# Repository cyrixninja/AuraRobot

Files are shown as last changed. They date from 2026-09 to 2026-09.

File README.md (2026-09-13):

# Aura — AI Social Assistance Robot

> A warm, voice-first companion robot that turns everyday conversation into a tangible, expressive interaction.

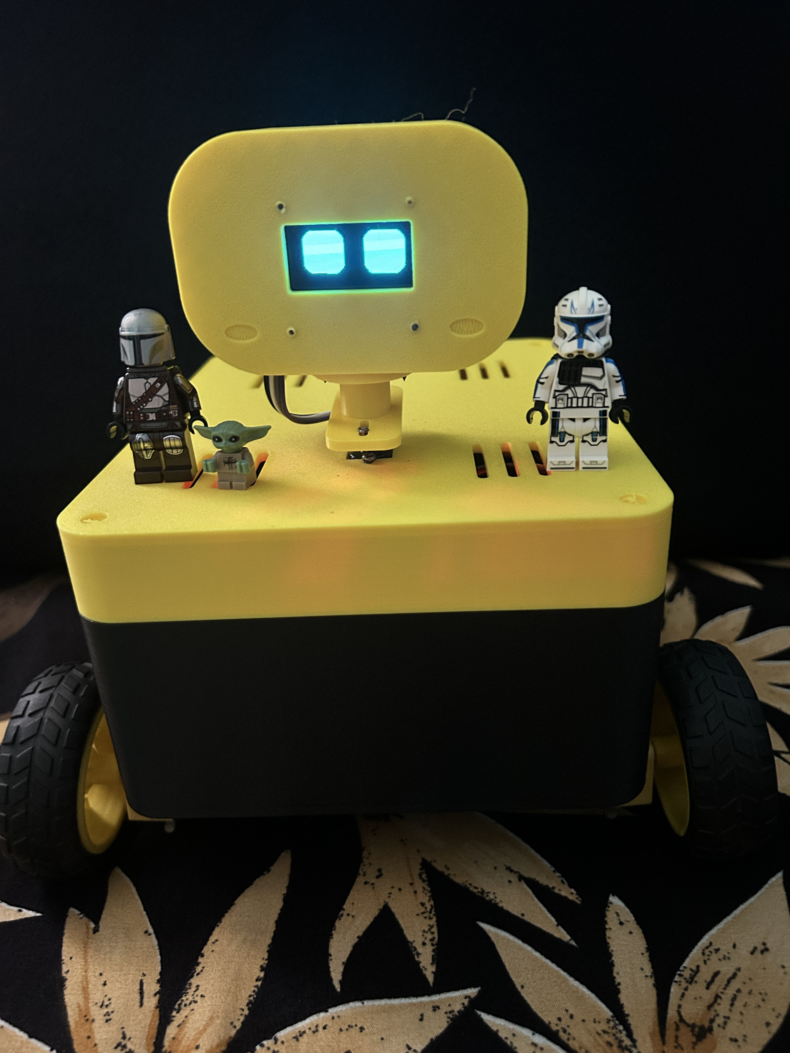
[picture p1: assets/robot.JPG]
Robot


Aura is an AI-powered social-assistance robot built with Arduino UNO Q and Arduino App Lab. It combines Gemini Live voice conversation with a physical personality: animated OLED eyes, a head that looks toward the user, expressive reactions, and safe, bounded movement. Rather than presenting another screen-based assistant, Aura makes AI feel present, approachable, and easier to engage with.

This project is designed for the **Social Assistance Robot** scenario in the [Invent the Future with Arduino UNO Q and App Lab contest](https://www.hackster.io/contests/invent-the-future-with-arduino-uno-q-and-app-lab). It demonstrates how the UNO Q can connect Linux-class AI and real-time embedded control in one friendly device.

## Introduction

Voice assistants are useful, but they can feel invisible, transactional, and difficult to connect with—especially for people who benefit from gentle social cues, simple interfaces, or encouragement to start a conversation. Aura explores a more human-centered alternative: a small companion that listens, speaks naturally, and visibly reacts.

When someone says hello, Aura greets them with a happy face and a small head gesture. When it is praised, curious, celebrating, or saying goodnight, its expression changes to match the moment. A user can ask a question, share an idea, or give a direct movement command without learning an app or menu. The result is a playful proof of concept for future social companions in homes, classrooms, maker spaces, and wellbeing-oriented experiences.

Aura is intentionally a **voice-first prototype**, not an autonomous navigation robot. It has no obstacle, bumper, cliff, camera, or identity sensors today. Its motion behavior is therefore conservative and always requires an explicit user command.

For a short submission-ready version, see [INTRODUCTION.md](INTRODUCTION.md).

## Project evidence and recreation guide

Aura is documented so a beginner can understand both what was built and how to rebuild it:

| Evidence | What it demonstrates |
| --- | --- |
| Assembled Aura robot | The finished wheeled companion with its expressive OLED head. |
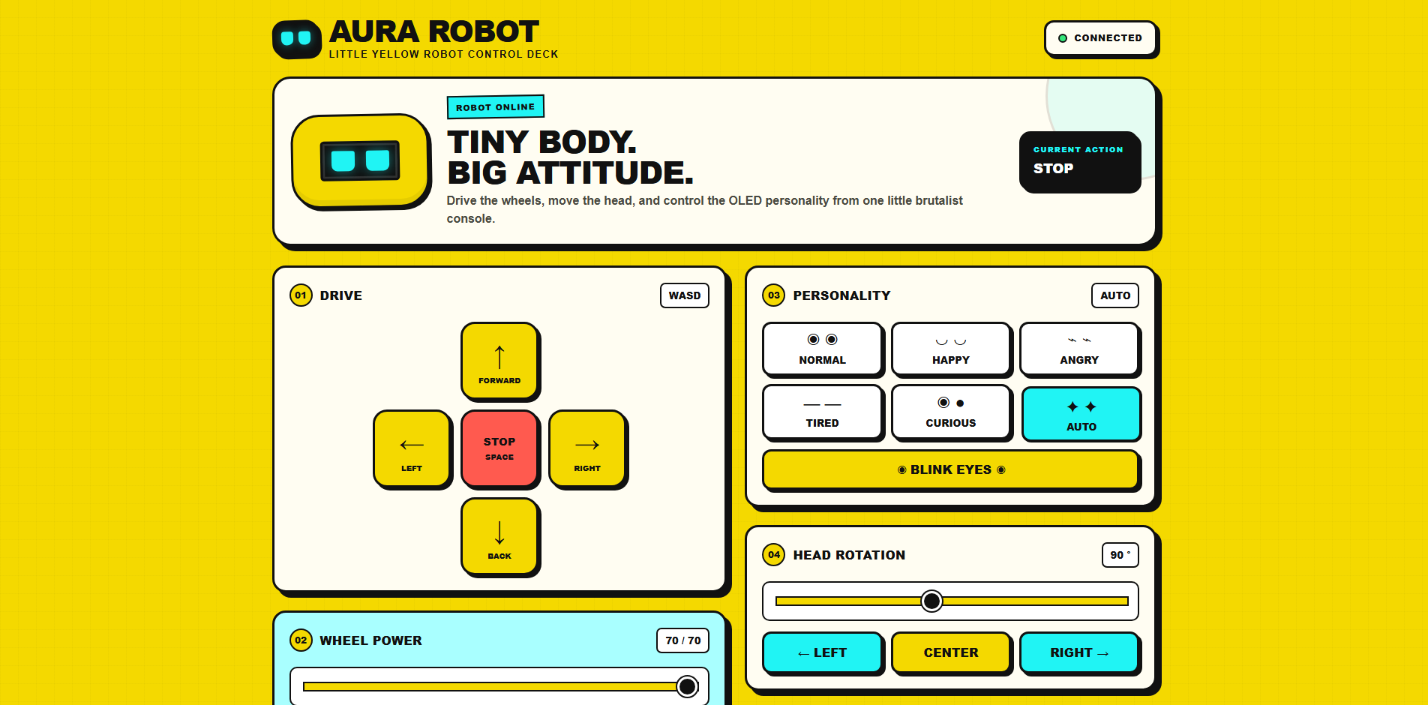
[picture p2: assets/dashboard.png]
Aura manual dashboard
|  | The dashboard used to check motors, head, eyes, and connection state. |
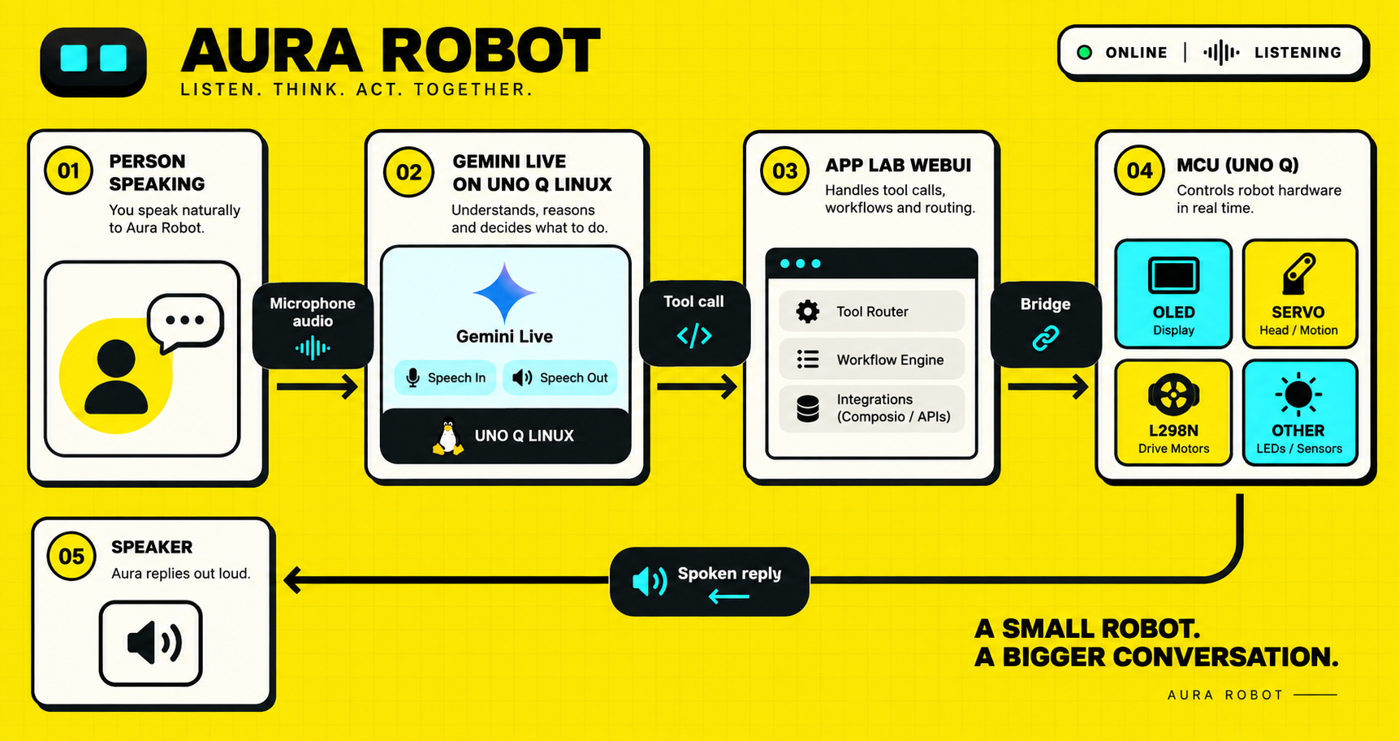
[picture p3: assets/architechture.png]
Aura architecture
|  | How Gemini Live, the UNO Q Linux side, App Lab, and the MCU cooperate. |
| [Circuit diagram](circuit_image.png) | The physical controller, motor driver, servo, and OLED wiring reference. |

Follow [BUILD_GUIDE.md](BUILD_GUIDE.md) as a linear beginner build. It explains the complete bill of materials, each used UNO Q connection, USB-C audio, safe power wiring, assembly, deployment, and verification.

## Why Arduino UNO Q and App Lab

Aura uses the UNO Q's dual-compute design in a way that is difficult to achieve with a conventional microcontroller alone:

| UNO Q capability | Aura implementation |
| --- | --- |
| Linux-side processing | Python streams microphone audio to Gemini Live, plays audio responses, manages voice turns, and interprets tool calls. |
| Real-time MCU control | The Arduino sketch drives the L298N, head servo, OLED animation, blink state, and timed motor stop. |
| Arduino Bridge | The App Lab Python service sends safe commands from Linux to the MCU. |
| App Lab WebUI | A browser dashboard provides transparent manual control, status, and a fallback interface during testing. |



## Innovation and real-world value

### Social impact

Aura makes conversational AI more approachable through visible non-verbal feedback: eye expressions, blinks, head gestures, and a warm speaking style. This can support low-pressure conversation practice, companionship activities, classroom engagement, and inclusive maker demonstrations. It does not claim to replace carers, therapists, teachers, or professional support; it is a platform for exploring more empathetic human-machine interaction.

### User experience

The primary interface is natural speech. Aura keeps spoken responses short, avoids exposing function names or technical details, and provides a familiar browser control deck for setup and manual testing. A user can say `Hello Aura`, `look right`, `move forward`, or `stop` instead of learning a command syntax.

### Technical innovation

The project separates language-model intent from low-level hardware control. Gemini receives only semantic actions such as `move_briefly`, `look`, `express`, and `stop_robot`; it never receives unrestricted PWM or raw pin access. The MCU enforces movement timing independently, which means ordinary 2.5-second motions stop even if the voice process disconnects.

### Scalability and future potential

Aura's semantic action layer makes it possible to add features without redesigning the conversational system. Future versions can add a camera for opt-in visual interaction, distance and cliff sensors for safer assisted navigation, local wake-word processing, personalized routines, multilingual modes, and privacy-preserving on-device models. The same interaction design can also scale from a desk companion to classroom or community installations.

### Sustainability and responsible design

Aura is modular: the mechanical shell, L298N, servo, display, App Lab application, and voice app can be repaired or upgraded independently. Its current low-speed, short-duration motion policy reduces unnecessary motor runtime. Audio is sent to Gemini Live for conversation, so deployments should clearly inform users about network use and handle API keys as secrets.

## Current capabilities

- Short, natural Gemini Live conversations with a warm companion personality.
- Automatic happy greeting gesture for `hello`, `hi`, and similar greetings.
- Normal movement at speed 70 for 2.5 seconds, followed by an MCU-enforced stop.
- Explicit continuous motion that stops when the user says `stop` or the voice app cannot renew its timed pulses.
- Head movement from 55° left to 135° right, eye blinking, temporary moods, and stationary cute gestures.

## Complete bill of materials

Quantities describe the reference build. Equivalent parts are fine when their voltage, current, dimensions, and connector requirements are compatible.

### Hardware

| Qty. | Part | Role / selection notes |
| --- | --- | --- |
| 1 | Arduino UNO Q | Runs Arduino App Lab, the Linux voice application, and the real-time MCU sketch. |
| 1 | L298N dual H-bridge motor-driver module | Drives the left and right DC motors. Its ENA and ENB pins must be available for PWM speed control. |
| 4 | DC BO and wheels | Left and right drive. Match them to the printed chassis and selected motor supply. |
| 1 | Compatible positional servo and two-arm horn | Turns Aura's head. The printed adapter expects a two-arm horn. |
| 1 | 128 × 64 SH1106 I²C OLED module | Animated face display. Use a module compatible with its selected logic voltage. |
| 1 set | Five supplied 3D-printed parts | Chassis, body, OLED head front, head rear cover, and horn adapter. |
| 1 | Regulated motor/servo power supply | Size it for the motors' stall current and the servo's peak current. Keep it separate from UNO Q USB logic power. |
| 1 | USB microphone | Voice input; connects through the UNO Q USB-C host path. |
| 1 | Powered AUX speaker or amplified speaker | Aura's voice output; connects through a USB-C audio adapter/hub. A passive speaker alone is not sufficient. |
| 1 | USB-C audio adapter or powered USB-C hub, plus data cables/adapters | Lets the UNO Q enumerate the microphone and speaker. Choose a data-capable, Linux-compatible device. |
| As needed | Jumper wires, motor wire, cable ties, M3 screws/nuts, and mounting hardware | Electrical connections, strain relief, and enclosure assembly. |

### Software and tools

| Item | Why it is needed |
| --- | --- |
| Arduino App Lab | Deploys the UNO Q MCU sketch, Linux Bridge service, and browser dashboard. |
| Python with the packages in [`robot/requirements.txt`](robot/requirements.txt) | Gemini Live audio streaming and safe semantic robot actions. |
| Gemini API key | Enables Gemini Live conversation. Keep it in `robot/.env`, never in source control. |
| A 3D printer and slicer | Prints the supplied STL enclosure files. |
| Small screwdriver, wire stripper/cutter, and a multimeter | Assembly, polarity checks, and debugging. |
| Web browser and SSH terminal | Dashboard control and starting the voice application. |

## Project layout

```text
Aura Robot/
├── Arduino Uno Q App/
│   ├── sketch/sketch.ino       # MCU: motors, servo, OLED, timed stop
│   ├── python/main.py          # Linux-side Bridge and WebUI API
│   └── assets/index.html       # Manual browser controller
├── 3D Assets/                   # Printable chassis, head, and servo parts
├── circuit_image.png            # Reference wiring diagram
├── assets/                      # Project photos, dashboard, architecture
├── BUILD_GUIDE.md                # Step-by-step beginner build and pin guide
├── robot/
│   ├── robot.py                # Gemini Live voice application
│   ├── robot_tools.py          # Safe HTTP robot actions
│   ├── requirements.txt        # Tested Python dependency versions
│   ├── .env.example            # Configuration template
│   └── README.md               # Voice app reference
└── README.md                   # This guide
```

## Mechanical build and electronics

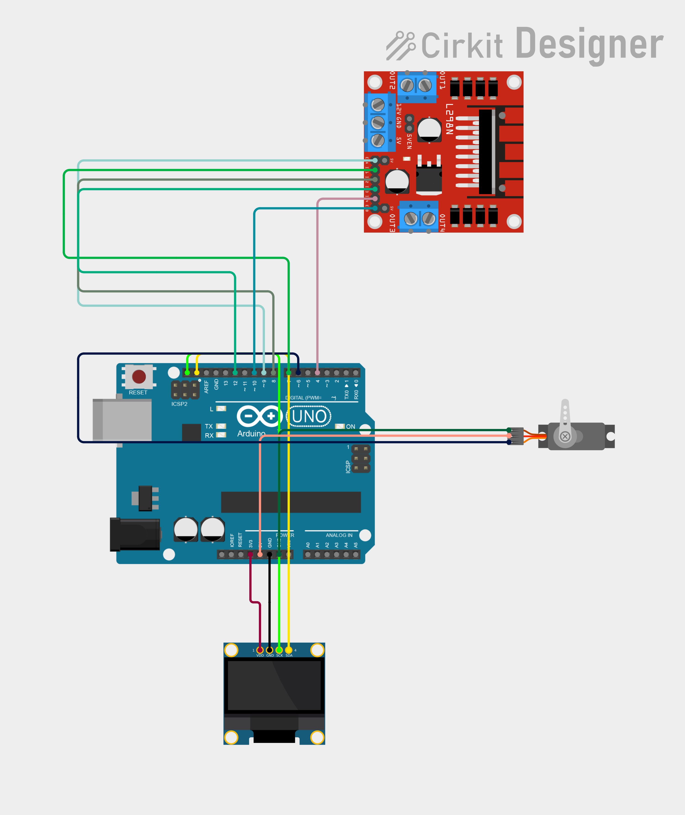
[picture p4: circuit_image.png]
Aura reference wiring diagram


The provided diagram is the reference for the physical build; the pin definitions in [`sketch.ino`](<Arduino Uno Q App/sketch/sketch.ino>) are the software source of truth. The full beginner sequence, including USB-C audio setup, is in [BUILD_GUIDE.md](BUILD_GUIDE.md). Build and test the robot before starting the voice application.

### 3D-printed parts

| Printable asset | Purpose |
| --- | --- |
| [`01_lower_chassis_8_round_holes.stl`](<3D Assets/01_lower_chassis_8_round_holes.stl>) | Lower wheeled chassis and mounting base. |
| [`02_body_cover_centred_servo.stl`](<3D Assets/02_body_cover_centred_servo.stl>) | Main body cover with a centered head-servo mount. |
| [`03_oled_head_front_M3.stl`](<3D Assets/03_oled_head_front_M3.stl>) | OLED face/head front; designed for M3 mounting hardware. |
| [`04_head_rear_cover.stl`](<3D Assets/04_head_rear_cover.stl>) | Rear cover that closes and protects the head assembly. |
| [`05_two_arm_horn_adapter.stl`](<3D Assets/05_two_arm_horn_adapter.stl>) | Adapter between the head and a two-arm servo horn. |

No print profile is included, so choose material, layer height, infill, and supports for your printer. Print a single fit-test part first if your printer tends to vary in hole size.

Suggested assembly order:

1. Print the five STL files and prepare the motors, wheels, servo, OLED, UNO Q, L298N, and suitable fasteners.
2. Secure the servo in the centered mount of the body cover. Before fitting the horn adapter, power the servo and center it with `/api/servo/90`.
3. Fit the two-arm horn adapter to the centered servo, then attach the head assembly. This avoids a crooked or mechanically blocked head range.
4. Install the OLED in the head front, using M3 hardware where the part requires it, then close the head with the rear cover.
5. Mount the electronics and cable runs on the lower chassis. Keep motor wires clear of the wheels and leave enough slack for the head to turn from 55° to 135°.

### Wiring map

Disconnect all power before wiring. Use the diagram above for placement and route the controller signals as follows:

| UNO Q connection | Connect to | Function and check |
| --- | --- | --- |
| D9 (PWM) | L298N ENA | Left-motor speed enable. Remove the ENA jumper on modules that fit one, otherwise PWM speed control is bypassed. |
| D7 | L298N IN1 | Left-motor direction input 1. |
| D8 | L298N IN2 | Left-motor direction input 2. |
| D10 (PWM) | L298N ENB | Right-motor speed enable. Remove the ENB jumper on modules that fit one. |
| D12 | L298N IN3 | Right-motor direction input 1. |
| D13 | L298N IN4 | Right-motor direction input 2. |
| D6 | Servo signal | Head control; the application restricts the physical target to 55°–135°. |
| SDA / SCL pins marked on the UNO Q | SH1106 OLED SDA / SCL | Hardware I²C data and clock. Do not substitute arbitrary digital pins. |
| GND | L298N GND, servo GND, OLED GND, supply negative | One common reference is required for all control signals. |
| Regulated logic supply | OLED VCC and servo V+ as required by their specifications | Check each module's voltage label before connection. |
| Regulated motor supply | L298N motor-power input | Size for motor stall current; follow the regulator/jumper notes printed on the specific L298N board. |

Connect the left motor to L298N `OUT1`/`OUT2` and the right motor to `OUT3`/`OUT4`. If a motor's direction is reversed after a wheels-raised test, set `LEFT_REVERSED` or `RIGHT_REVERSED` in the sketch rather than changing the voice behavior.

### USB-C microphone and AUX speaker

Audio does **not** use UNO Q GPIO pins. The reference build uses a normal USB microphone and a powered 3.5 mm AUX speaker through the UNO Q USB-C host/audio path:

1. Connect a data-capable USB-C audio adapter or powered USB-C hub to the UNO Q.
2. Connect the USB microphone to that host path.
3. Connect the AUX speaker to the adapter's 3.5 mm audio output. Use an active/powered speaker or an external amplifier; a raw passive speaker cannot be driven directly.
4. Use a data-capable USB-C cable, not a charging-only cable. If microphone and speaker are separate USB devices, use a powered hub that exposes both to Linux.
5. On the UNO Q, list the detected devices with `python3 -c "import sounddevice as sd; print(sd.query_devices())"`, then put identifying names in `INPUT_DEVICE` and `OUTPUT_DEVICE` in `robot/.env`.

The voice process mutes its microphone stream while Aura speaks and waits briefly before resuming it, reducing speaker echo. Keep `ALLOW_BARGE_IN=false` unless you add acoustic echo cancellation or headphones.

The diagram does not specify one universal battery or supply: choose one rated for your specific motors and servo, including their startup/stall current. Do **not** power the motors or servo from the UNO Q USB/logic 5 V rail. Disconnect power while changing wiring, first test with the wheels raised, and verify `/api/stop` before placing Aura on the floor.

## Code, contribution, and creativity

| Contribution | Where it lives | Why it matters |
| --- | --- | --- |
| Real-time robot control | [`sketch.ino`](<Arduino Uno Q App/sketch/sketch.ino>) | Commented MCU code animates the OLED, drives the servo and L298N, and enforces a timed motor stop independently of the network. |
| App Lab Bridge and dashboard API | [`Arduino Uno Q App/python/main.py`](<Arduino Uno Q App/python/main.py>) | Connects the Linux and MCU sides and enables transparent manual tests. |
| Gemini Live conversation | [`robot/robot.py`](robot/robot.py) | Captures USB microphone audio, handles turn taking/reconnection, plays Aura's voice, and keeps its personality concise and warm. |
| Safe action boundary | [`robot/robot_tools.py`](robot/robot_tools.py) | Gives Gemini semantic actions rather than raw pins or PWM: short move, continuous move, stop, look, emotion, blink, and cute gestures. |

Aura's creative contribution is that voice conversation has an embodied, readable response: animated eyes, head motion, and a gentle physical personality make the assistant feel present without handing unsafe low-level control to the model. UNO Q's Linux side handles conversational AI while its MCU independently maintains predictable motion limits. This fresh combination makes the robot approachable for homes, classrooms, maker spaces, and social-assistance demonstrations.

## Setup

### 1. Deploy the App Lab project

Open `Arduino Uno Q App` in Arduino App Lab and click **Run**. This flashes the MCU sketch, deploys the Linux-side app, and starts the WebUI service.

Open the manual dashboard and make sure it reports **Connected**. With wheels raised, test stop, servo left/center/right, blink, and wheel directions. See [Arduino UNO Q App guide](<Arduino Uno Q App/README.md>) for its API and deployment details.

### 2. Configure the voice app

Copy the whole `robot` directory to the UNO Q. Keep `robot.py` and `robot_tools.py` from the same version.

```bash
cd robot
python3 -m venv venv
source venv/bin/activate
python -m pip install -r requirements.txt
cp .env.example .env
```

Set `GEMINI_API_KEY`, audio-device names, and the App Lab WebUI base URL in `.env`. This project defaults to `http://127.0.0.1:7000`; use the exact URL/port shown by App Lab if yours differs, and do not add `/api` to it.

Verify the connection:

```bash
curl http://127.0.0.1:PORT/api/status
```

Replace `PORT` with the App Lab WebUI port in your `.env`.

The result should include `"success": true`, safe speed `70`, and servo limits `55` and `135`.

### 3. Start Aura

```bash
cd robot
source venv/bin/activate
python3 -B robot.py
```

`-B` avoids stale bytecode during SSH iteration. Wait for **Aura is ready**, then say `Hello Aura`.

## Voice commands

| Say | Result |
| --- | --- |
| `Hello Aura` | Head-and-eye greeting, then Aura responds. |
| `Move forward` | Forward at speed 70 for 2.5 seconds. |
| `Turn left` | Spins left at speed 70 for 2.5 seconds. |
| `Move continuously forward` | Moves until told to stop; stay nearby. |
| `Stop` | Immediately stops wheel motion. |
| `Look left` / `look right` | Moves head to 55° / 135°. |
| `Blink` | Blinks the OLED eyes. |
| `Be happy` | Shows a temporary happy expression. |
| `Celebrate with me` | Performs a stationary happy gesture. |

Aura will not move for a hypothetical or unclear request. Use a direct command.

## Update order

1. Click **Run** in Arduino App Lab after changing `sketch.ino` or `main.py`.
2. Copy both `robot/robot.py` and `robot/robot_tools.py` together after changing either one.
3. Restart with `python3 -B robot.py`.
4. Test wheels raised before testing on the floor.

If you see `RobotController has no attribute move_briefly`, the two voice-app files are different versions. Sync both files and restart in the `robot` directory.

## Troubleshooting

| Symptom | Check |
| --- | --- |
| `GEMINI_API_KEY missing` | Add a valid key to `robot/.env`. |
| Audio device not found | List devices with `python3 -c "import sounddevice as sd; print(sd.query_devices())"`, then update `.env`. |
| No `You:` after Aura is ready | Check microphone selection and lower `MIC_VOICE_RMS_THRESHOLD` in `.env` from `1200` to `800`, then restart. |
| `You:` appears but there is no reply | The 12-second voice watchdog now closes and reconnects a stale Live session. Update all voice files and dependencies if that recovery message does not appear. |
| Opening handshake times out | Keep the process running: it now retries with exponential backoff. Check internet/DNS and the API key if every attempt fails. |
| `another Aura voice process is already running` | Stop the older `robot.py` process first. Two processes cannot safely share the USB microphone and speaker. |
| `[Aura] Robot action failed` | Test `curl http://127.0.0.1:PORT/api/status` and redeploy App Lab. |
| `[Aura] Greeting gesture unavailable` | Deploy the current App Lab project and sync both voice-app files. |

See [robot/README.md](robot/README.md) for configuration and logs, and the [Arduino UNO Q App guide](<Arduino Uno Q App/README.md>) for the HTTP API.

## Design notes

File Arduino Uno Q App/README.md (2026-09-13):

# Arduino UNO Q App Lab controller

This App Lab project is split across the UNO Q’s two processors:

- `sketch/sketch.ino` runs on the MCU. It drives the L298N, servo, SH1106 OLED face, timed-move deadline, blinking, and automatic expressions.
- `python/main.py` runs on the UNO Q Linux side. It exposes the WebUI HTTP endpoints and forwards requests over Arduino Bridge to the MCU.
- `assets/index.html` is the manual browser dashboard.

## Deploy

Open this folder as an Arduino App Lab project and click **Run** whenever `sketch.ino` or `main.py` changes. App Lab flashes the MCU and starts the Linux application together.

Before using Gemini, open the dashboard and verify it reports **Connected**. Test with wheels raised first.

The root [mechanical build and electronics guide](../README.md#mechanical-build-and-electronics) documents the supplied circuit diagram and five printable enclosure parts. The pin mapping below matches the reference build.

## Manual Control Dashboard

Aura Robot dashboard

The App Lab WebUI is the manual control deck for wiring checks, safe demonstrations, and voice-app fallback. It checks `/api/status` every five seconds and shows **Connected** only when the controller responds. It initializes Aura at speed `70`, head center `90°`, and automatic face mode.

| Control | Use |
| --- | --- |
| Drive pad | Press and hold Forward, Back, Left, or Right; release to stop. The control uses direct drive only while a person is actively holding it. |
| Stop | Sends `/api/stop` immediately. Use it before changing any wiring. |
| Wheel Power | Sets speed from 0–70; begin at 70 or lower. |
| Personality | Select Normal, Happy, Angry, Tired, Curious, or Auto OLED behavior. |
| Blink Eyes | Triggers one OLED blink. |
| Head Rotation | Adjusts the head between 55° and 135°; Center returns it to 90°. |

Keyboard shortcuts work while the dashboard is open:

| Keys | Action |
| --- | --- |
| `W` / `A` / `S` / `D` or arrow keys | Hold to drive forward / left / back / right; releasing the key stops. |
| `Space` | Stop immediately. |
| `Q` / `E` / `C` | Head 5° left / 5° right / center at 90°. |
| `1` / `2` / `3` / `4` / `5` / `0` | Normal / Happy / Angry / Tired / Curious / Auto face. |
| `B` | Blink eyes. |

Safe preflight: lift the wheels, verify **Connected**, test Stop, Blink, servo center/left/right, then briefly test each drive direction. Put Aura on the floor only after these checks succeed and keep the Stop button accessible.

## Enforced limits

| Item | Limit |
| --- | --- |
| Wheel speed | 0–70 |
| Head left | 55° |
| Head center | 90° |
| Head right | 135° |
| Timed move | 100–5,000 ms |
| Temporary expression | 500–5,000 ms |

The MCU owns the timed-move deadline. `/api/move` is therefore suitable for short voice movements even if the Linux app stops responding.

## HTTP API

Replace `BASE` with the URL configured as `ROBOT_API_BASE` in `robot/.env`.

| Request | Description |
| --- | --- |
| `GET BASE/api/status` | Controller identity and enforced limits. |
| `GET BASE/api/drive/{left}/{right}` | Manual latched wheel drive. Each side is `-1`, `0`, or `1`; always follow with stop. |
| `GET BASE/api/move/{left}/{right}/{duration_ms}` | MCU-timed wheel move. Each side is `-1`, `0`, or `1`. |
| `GET BASE/api/stop` | Stops both wheels immediately. |
| `GET BASE/api/speed/{value}` | Sets speed, clamped to 0–70. |
| `GET BASE/api/servo/{angle}` | Turns the head, clamped to 55–135°. |
| `GET BASE/api/emotion/{value}` | Persistent mood: normal `0`, happy `1`, angry `2`, tired `3`, curious `4`, automatic `5`. |
| `GET BASE/api/express/{value}/{duration_ms}` | Temporary mood followed by automatic face behavior. |
| `GET BASE/api/blink` | Triggers an eye blink. |

## Quick API test

After App Lab starts the project, run these commands from the UNO Q or another machine that can reach the WebUI server:

```bash
curl http://HOST:PORT/api/status
curl http://HOST:PORT/api/servo/90
curl http://HOST:PORT/api/blink
curl http://HOST:PORT/api/move/1/1/2500
```

Replace `HOST:PORT` with the WebUI address configured in `robot/.env`.

Keep wheels raised for the movement test. The direct `/api/drive` route is for the manual dashboard; Gemini uses `/api/move` so normal voice commands time out on the MCU.

Return to the root [README](../README.md) for the complete setup and safety guide.

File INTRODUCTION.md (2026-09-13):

# Aura — AI Social Assistance Robot

## One-line pitch

Aura is a warm, expressive companion robot that uses Gemini Live Flash and Arduino UNO Q to turn ordinary voice conversation into safe, visible, physical interaction.

## Contest introduction

Aura explores how AI can feel less like a command line and more like a friendly presence. Built on Arduino UNO Q and Arduino App Lab, it listens to a user through Gemini Live, replies in a short natural voice, and shows personality through animated OLED eyes, a moving head, blinks, moods, and carefully bounded movement.

The project addresses the **Social Assistance Robot** scenario by making interaction approachable and low pressure. A user can greet Aura, ask a question, share an idea, or give a simple instruction without learning a mobile app or technical interface. Aura responds with both voice and body language: it looks around when curious, becomes happy during praise or celebration, and offers a gentle greeting when someone says hello. These small cues make the interaction clearer, more engaging, and more inviting for homes, classrooms, maker spaces, and wellbeing-oriented experiences.

Arduino UNO Q is central to the design. Its Linux side runs the Python voice application, Gemini Live connection, audio handling, and tool-call orchestration. Its microcontroller side handles deterministic L298N motor control, servo movement, OLED animation, and a timed movement deadline. Arduino Bridge and App Lab connect those two worlds, while the App Lab WebUI provides a transparent manual dashboard for setup, testing, and fallback control.

Aura is deliberately not presented as an autonomous robot. The current prototype has no camera, obstacle sensor, bumper, or cliff sensor, so it moves only after a clear direct instruction. Normal movements run at speed 70 for 2.5 seconds and are stopped by the MCU even if the voice process disconnects. Continuous movement is explicitly requested and implemented through short renewed timed pulses. This safety-first design keeps the prototype honest while leaving a clear path to future sensor-assisted mobility.

The project is modular and scalable. Its semantic action layer gives the language model safe actions such as `look`, `express`, `move_briefly`, and `stop_robot`, rather than unrestricted hardware access. Future versions can add opt-in vision, distance and cliff sensing, wake-word detection, local models, routines, multilingual modes, and accessibility-focused interaction flows without replacing the core architecture.

Aura demonstrates that a powerful AI robot does not have to be intimidating. With UNO Q and App Lab, it becomes possible to combine real-time embedded reliability with expressive conversational AI in a repairable, approachable companion platform.

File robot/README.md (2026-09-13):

# Aura voice application

`robot.py` streams microphone audio to Gemini Live, plays Aura’s voice, and handles model-requested robot actions. `robot_tools.py` is the safety boundary: Gemini receives semantic actions, never raw L298N PWM values.

## Install dependencies

Use the Python environment that has access to the USB microphone and speaker:

```bash
python3 -m pip install -r requirements.txt
```

## Configure and run

```bash
cd robot
cp .env.example .env
python3 -B robot.py
```

Set `GEMINI_API_KEY`, `INPUT_DEVICE`, `OUTPUT_DEVICE`, and `ROBOT_API_BASE` in `.env` before starting. To discover audio-device names:

```bash
python3 -c "import sounddevice as sd; print(sd.query_devices())"
```

Start from the `robot` directory so `robot.py` imports the matching `robot_tools.py`.

For an existing `~/gemini-live` installation, copy `robot.py`,
`robot_tools.py`, `requirements.txt`, and the new settings from `.env.example`,
then upgrade the active environment before restarting:

```bash
cd ~/gemini-live
source venv/bin/activate
python -m pip install -r requirements.txt
python -B robot.py
```

Keep your existing API key when updating `.env`.

## Configuration reference

| Variable | Purpose | Default |
| --- | --- | --- |
| `GEMINI_API_KEY` | Gemini API key. Required. | — |
| `GEMINI_MODEL` | Gemini Live model. | `gemini-3.1-flash-live-preview` |
| `GEMINI_VOICE` | Gemini prebuilt voice. | `Puck` |
| `INPUT_DEVICE` | Substring matching the microphone device. | `Maono Elf` |
| `OUTPUT_DEVICE` | Substring matching the speaker device. | `AB13X USB Audio` |
| `INPUT_RATE` | Preferred microphone sample rate. | `16000` |
| `INPUT_BLOCK_SIZE` | PortAudio capture block size; `0` lets the audio host choose. | `0` |
| `INPUT_LATENCY` | PortAudio capture-latency policy. | `high` |
| `AUDIO_CHUNK_MS` | Audio accumulated per Gemini Live packet (clamped to the 20–40 ms recommended range). | `40` ms |
| `MIC_VOICE_RMS_THRESHOLD` | Local voice-detection level used for manual activity detection. | `1200` |
| `LOCAL_SPEECH_MIN_SECONDS` | Minimum sustained local sound before Aura opens a manual speech turn. | `0.25` s |
| `LOCAL_SPEECH_SILENCE_SECONDS` | Local quiet time used to mark an utterance complete. | `0.9` s |
| `VOICE_RESPONSE_TIMEOUT_SECONDS` | Reconnect if locally detected speech gets no Gemini activity. | `12` s |
| `WATCHDOG_INTERVAL_SECONDS` | Voice-health check interval. | `1` s |
| `VAD_MODE` | `manual` sends local speech start/end markers; `automatic` leaves detection to Gemini. | `manual` |
| `ALLOW_BARGE_IN` | Keep listening while Aura speaks; use only with headphones or echo cancellation. | `false` |
| `OUTPUT_GAIN` | Software speaker gain. | `2.0` |
| `ECHO_COOLDOWN` | Delay before re-enabling the mic after Aura speaks; clamped to at least 0.7 s. | `0.7` s |
| `RECONNECT_INITIAL_SECONDS` | First retry delay after a Gemini connection failure. | `3` s |
| `RECONNECT_MAX_SECONDS` | Maximum exponential-retry delay. | `30` s |
| `ROBOT_API_BASE` | App Lab WebUI base URL, without `/api`. | `http://127.0.0.1:7000` |
| `ROBOT_HTTP_TIMEOUT` | Timeout for a WebUI request. | `2.0` s |

## Voice-turn behavior

Aura defaults to manual activity detection: sustained microphone energy opens a Gemini Live turn and local silence closes it. This avoids a noisy USB microphone leaving server-side VAD waiting forever. Set `VAD_MODE=automatic` only if Gemini consistently finalizes your speech in your room; automatic mode uses high start/end sensitivity. During speaker playback, microphone chunks are discarded so Aura does not hear itself. Aura waits 0.7 seconds after playback before listening again to let speaker echo fade.

USB microphones often expose only 44.1 or 48 kHz. Aura captures at the device's supported rate, groups host callback blocks into stable 40 ms packets, then resamples them to Gemini's native 16 kHz mono PCM before sending. Audio starts only after the websocket connects.

The local voice watchdog reports microphone health without printing from the real-time callback. If packets stop, or a locally detected utterance receives no Gemini turn activity, Aura closes the stale session and reconnects. Context compression and session-resumption handles keep long-running conversations usable across planned server connection renewals.

A Linux process lock prevents two copies of `robot.py` from competing for the same USB microphone and speaker. The lock is released automatically when the running process exits, including after most crashes.

| Log | Meaning |
| --- | --- |
| `You: ...` | Gemini finalized what Aura heard. |
| `Aura: ...` | Aura’s spoken response transcript. |
| `[Aura] ...` | A physical action or connection needs attention. Aura retries transient connection failures automatically. |

## Gemini actions

| Action | Constraint |
| --- | --- |
| `move_briefly` | Speed 70, 2.5 seconds, MCU-enforced stop. |
| `start_continuous_motion` | Explicit request only; renewed 1.2-second timed pulses. |
| `stop_robot` | Stops wheels and cancels continuous-motion renewal. |
| `look` | Left 55°, center 90°, right 135°. |
| `express` | Temporary normal, happy, angry, tired, or curious mood. |
| `blink` | One OLED eye blink. |
| `do_cute_action` | Stationary greet, celebrate, or think gesture. |

Short greetings are handled locally from Gemini’s finalized transcript, so the physical greeting does not depend on the model selecting a tool.

## Deployment rule

Always copy `robot.py`, `robot_tools.py`, and `requirements.txt` together. Replacing only one Python source file can cause missing-method errors such as `RobotController has no attribute move_briefly`.

See the root [README](../README.md) for complete setup, safety, and WebUI guidance.

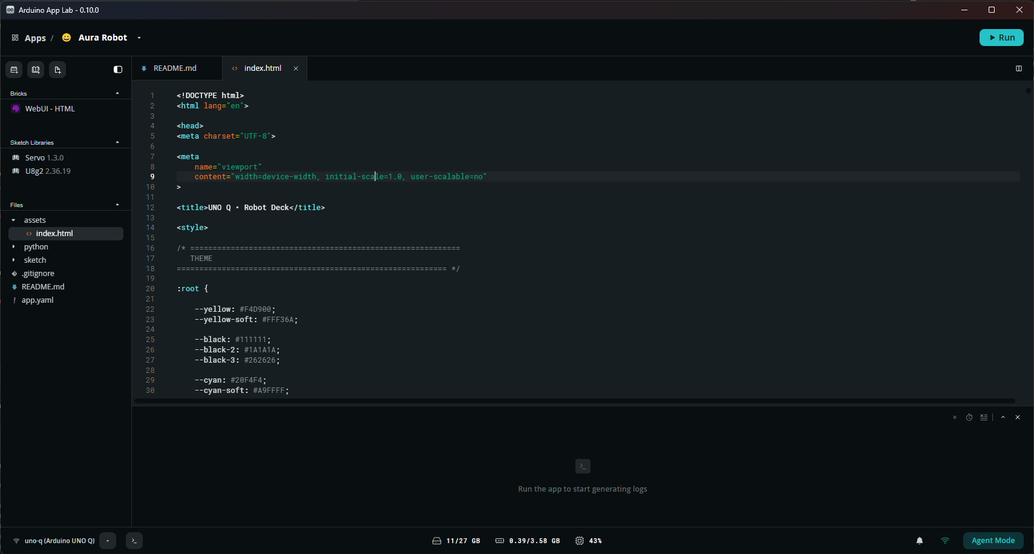
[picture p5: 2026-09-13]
assets/app_lab.png

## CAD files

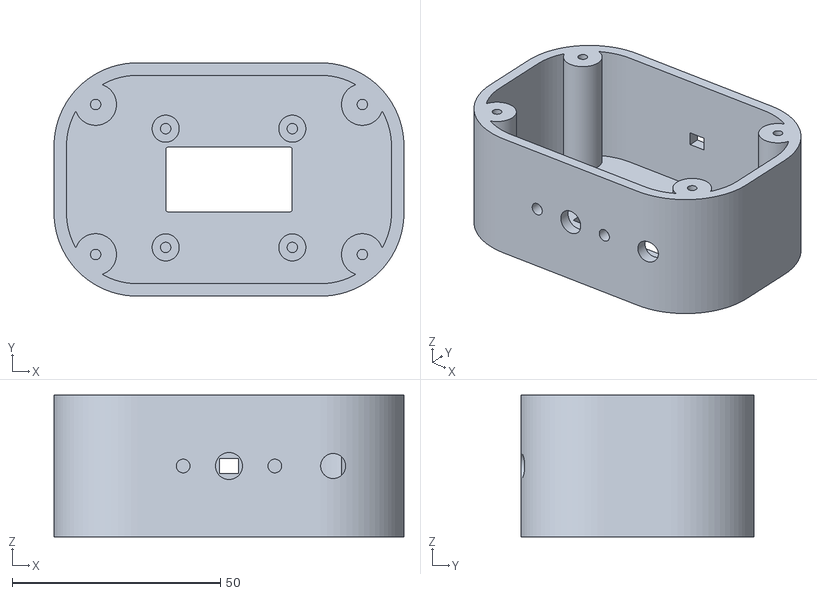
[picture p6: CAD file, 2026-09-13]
3D Assets/03_oled_head_front_M3.stl
84.0 x 56.0 x 34.0

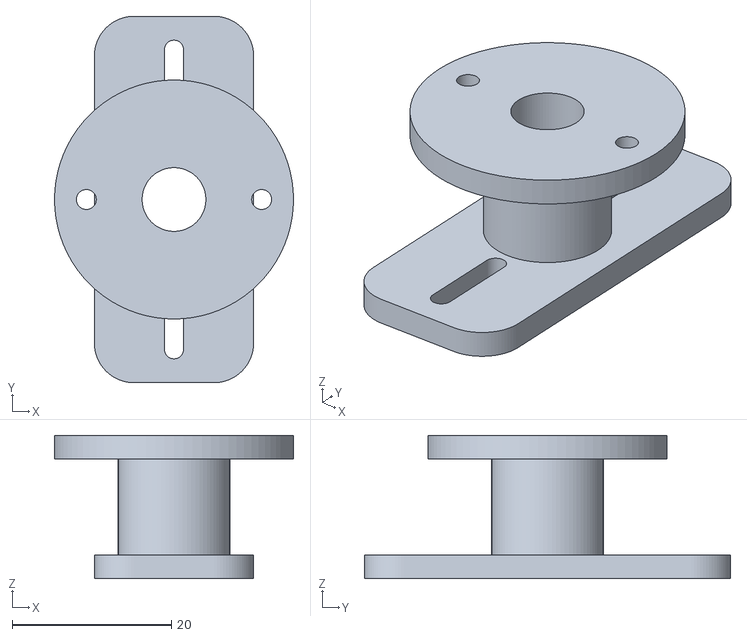
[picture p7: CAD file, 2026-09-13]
3D Assets/05_two_arm_horn_adapter.stl
30.0 x 46.0 x 18.0

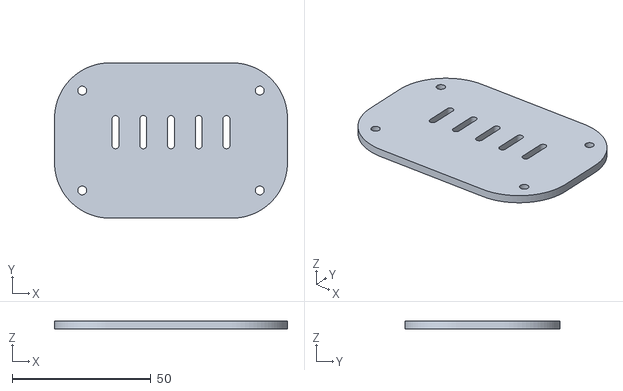
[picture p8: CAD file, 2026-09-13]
3D Assets/04_head_rear_cover.stl
84.0 x 56.0 x 2.80

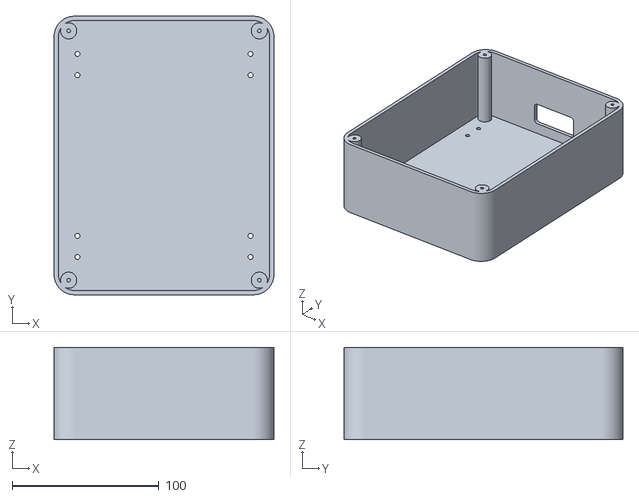
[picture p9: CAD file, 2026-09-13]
3D Assets/01_lower_chassis_8_round_holes.stl
150.0 x 190.0 x 63.0

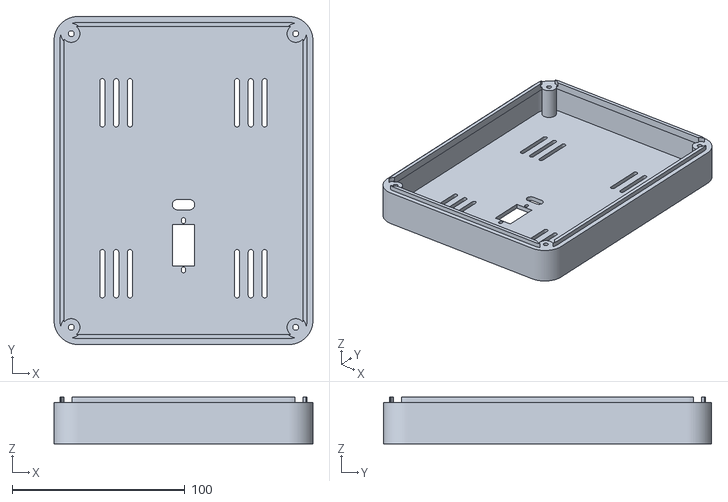
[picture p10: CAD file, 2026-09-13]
3D Assets/02_body_cover_centred_servo.stl
150.0 x 190.0 x 27.0

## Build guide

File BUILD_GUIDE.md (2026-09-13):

# Build Aura from the supplied files

This is the step-by-step recreation guide for Aura, a voice-first Arduino UNO Q companion robot. Read the [root README](README.md) first for the project story, photographs, architecture, complete bill of materials, and safety boundaries.

## What you are building

Aura is a two-wheel expressive robot. An Arduino UNO Q runs two cooperating programs: the MCU sketch makes the OLED face, servo head, and L298N motors responsive in real time, while the Linux side runs Gemini Live voice conversation. A USB microphone hears the user and a powered AUX speaker plays Aura's reply. Arduino App Lab bridges the two sides and provides a manual dashboard.

Finished Aura

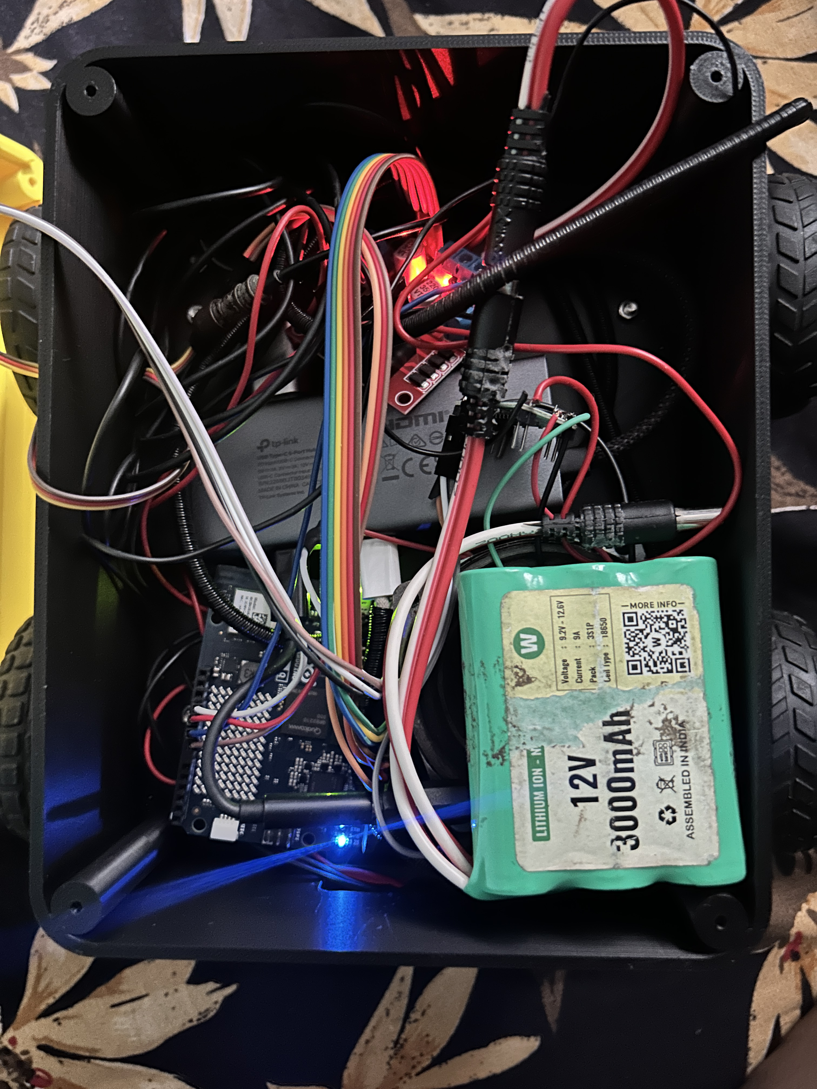
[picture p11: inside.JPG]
Inside Aura: UNO Q, wiring, and battery


## Before you start

- Print or open the [circuit diagram](circuit_image.png) beside your workbench.
- Gather every part in the [complete BOM](README.md#complete-bill-of-materials).
- Keep the motor and servo supply disconnected until all signal wiring is checked.
- Do the first motor test with the wheels off the floor.
- Aura has no obstacle, bumper, or cliff sensors. Never leave it moving unattended.

## 1. Print and assemble the enclosure

Print the files in [`3D Assets`](<3D Assets>) in this order:

1. [`01_lower_chassis_8_round_holes.stl`](<3D Assets/01_lower_chassis_8_round_holes.stl>) — lower chassis.
2. [`02_body_cover_centred_servo.stl`](<3D Assets/02_body_cover_centred_servo.stl>) — body cover and servo mount.
3. [`03_oled_head_front_M3.stl`](<3D Assets/03_oled_head_front_M3.stl>) — OLED face front with M3 mounting points.
4. [`04_head_rear_cover.stl`](<3D Assets/04_head_rear_cover.stl>) — head back cover.
5. [`05_two_arm_horn_adapter.stl`](<3D Assets/05_two_arm_horn_adapter.stl>) — link between head and two-arm servo horn.

No slicer profile is included. Use settings appropriate for your material and printer, and fit-test holes before forcing screws through them.

Mount the motors and wheels in the lower chassis. Fit the servo into the centered body mount, but **do not** attach the printed horn adapter yet. Install the OLED in the front head part, route its four wires safely through the neck, and close the head with the rear cover. Leave enough slack for the head to turn without pulling on the OLED wires. Reserve space for the battery low in the chassis, secure it so it cannot reach a wheel or shift into exposed wiring, and keep its leads away from sharp printed edges.

After the electronics are powered and the dashboard works, call `/api/servo/90` to center the servo. Only then attach the two-arm horn adapter and the head. This is important: attaching it before centering can make Aura's 55°–135° head range hit the mechanical stops.

## 2. Wire the UNO Q, L298N, servo, and OLED

Circuit diagram

All connections below are derived from the pin constants in [`Arduino Uno Q App/sketch/sketch.ino`](<Arduino Uno Q App/sketch/sketch.ino>). Make every connection with power disconnected.

### UNO Q digital-pin table

| UNO Q pin | Wire to | Purpose |
| --- | --- | --- |
| D6 | Servo signal | Moves the head; firmware limits commands to 55°–135°. |
| D7 | L298N IN1 | Left motor direction. |
| D8 | L298N IN2 | Left motor direction. |
| D9 (PWM) | L298N ENA | Left motor speed. |
| D10 (PWM) | L298N ENB | Right motor speed. |
| D12 | L298N IN3 | Right motor direction. |
| D13 | L298N IN4 | Right motor direction. |
| SDA | OLED SDA | I²C data. Use the UNO Q pin physically marked SDA/I²C. |
| SCL | OLED SCL | I²C clock. Use the UNO Q pin physically marked SCL/I²C. |
| GND | L298N GND, servo GND, OLED GND, supply negative | Mandatory shared electrical reference. |

### L298N and motor side

1. If your L298N module has ENA and ENB jumpers, remove them. D9 and D10 need direct access to ENA/ENB for PWM speed control.
2. Connect `OUT1` and `OUT2` to the left motor; connect `OUT3` and `OUT4` to the right motor.
3. Connect the dedicated motor supply to the L298N motor-power input and its negative terminal to L298N GND.
4. Connect L298N GND to UNO Q GND. Without this common ground, the direction and speed signals have no reliable reference.
5. Follow the voltage-regulator jumper instructions printed on your exact L298N module. Do not use its 5 V pin to back-power the UNO Q.

If left or right travel is backward during a safe test, set `LEFT_REVERSED` or `RIGHT_REVERSED` to `true` in the sketch for that side. This preserves the meaning of spoken directions.

### Servo and OLED side

1. Connect the servo signal lead to D6, its ground to the common ground, and its positive lead to a regulated supply suitable for the specific servo.
2. Connect OLED SDA and SCL to the dedicated UNO Q I²C header pins, OLED GND to common ground, and OLED VCC only to the voltage accepted by that display module.
3. Keep the motor/servo power wiring physically away from the OLED and audio cables where possible. Secure all wires so wheel movement and head rotation cannot pull them loose.

Never run the motors or servo from the UNO Q USB/logic 5 V rail. Choose a separate regulated supply that can handle motor stall current and the servo's short current peaks. Supply negative, L298N GND, UNO Q GND, OLED GND, and servo GND must be common.

### Reference battery and power checks

The interior photo shows the installed reference battery: a 3S 18650 Li-ion pack marked `12 V`, `30,000 mAh`, `9.2–12.6 V`, and `9 A`.

Reference battery installed inside Aura

Those markings identify the photographed pack; they are not a substitute for the pack's charger/BMS documentation, and they do not prove the voltage requirements of a replacement part. Before connecting it:

1. Keep the battery unplugged and verify the polarity at the connector with a multimeter.
2. Add an appropriately rated inline fuse close to battery positive and an accessible power switch.
3. Connect the battery only to the correctly marked motor-power input. Use a suitable regulator for any servo/OLED rail that needs lower voltage.
4. Connect all grounds together, then re-check for shorts before first power-up.
5. Charge the Li-ion pack only with the charger and protection arrangement specified for that exact battery. Do not charge it through UNO Q or an unknown connector.

## 3. Connect the microphone and speaker through USB-C

The microphone and speaker use the UNO Q's USB-C host/audio path; no GPIO pins are used for audio.

1. Attach a data-capable USB-C audio adapter or a powered USB-C hub to the UNO Q.
2. Connect the normal USB microphone to the adapter/hub.
3. Connect a **powered** AUX speaker to the adapter's 3.5 mm AUX output. A passive speaker needs an amplifier and must not be connected to a GPIO pin.
4. Use data-capable USB-C leads. Charging-only leads cannot carry audio-device data.
5. If the microphone and speaker are separate USB devices, use a powered hub that lets the UNO Q Linux side see both at once.

After software setup, verify the device names with:

```bash
python3 -c "import sounddevice as sd; print(sd.query_devices())"
```

Set matching substrings in `robot/.env`:

```dotenv
INPUT_DEVICE=your microphone name
OUTPUT_DEVICE=your USB-C audio/speaker name
```

Aura deliberately discards microphone audio while it plays a reply, then waits briefly before listening again. This reduces the chance that the microphone hears the AUX speaker and creates a false conversation turn.

## 4. Deploy the UNO Q controller

1. Open [`Arduino Uno Q App`](<Arduino Uno Q App>) in Arduino App Lab.
2. Click **Run**. App Lab flashes [`sketch/sketch.ino`](<Arduino Uno Q App/sketch/sketch.ino>) to the MCU and starts [`python/main.py`](<Arduino Uno Q App/python/main.py>) on the Linux side.
3. Open the WebUI dashboard and confirm it says **Connected**.
4. With wheels raised, test stop, blink, servo center, servo left, servo right, then each motor direction. The [App Lab controller guide](<Arduino Uno Q App/README.md>) lists the test API calls.

Manual Control Dashboard

Use this dashboard as Aura's manual safety and demonstration interface. Hold a drive-pad button (or `W`/`A`/`S`/`D` or arrow key) only for the movement you want; release it to stop. `Space` sends Stop immediately. Set Wheel Power to 70 or lower, use the personality buttons and Blink Eyes to verify the OLED, and use Head Rotation to check left, center, and right before relying on Gemini voice commands. Its complete controls and keyboard shortcuts are documented in the [App Lab controller guide](<Arduino Uno Q App/README.md#manual-control-dashboard>).

The MCU owns the normal movement deadline. A 2.5-second command stops at the MCU even if the Python voice app has disconnected.

## 5. Configure and start Gemini Live

Copy the entire [`robot`](robot) folder to the UNO Q so `robot.py`, `robot_tools.py`, `requirements.txt`, and `.env.example` stay in sync.

```bash
cd robot
python3 -m venv venv
source venv/bin/activate
python -m pip install -r requirements.txt
cp .env.example .env
```

Edit `.env` and set your Gemini API key, the two audio device names found in the previous step, and the App Lab server address. Do not commit the completed `.env` file.

```dotenv
GEMINI_API_KEY=your_key_here
INPUT_DEVICE=your microphone name
OUTPUT_DEVICE=your speaker name
ROBOT_API_BASE=http://127.0.0.1:7000
```

Use the port shown by App Lab if it is not `7000`. Confirm that the controller is reachable before starting voice:

```bash
curl http://127.0.0.1:7000/api/status
```

Then start Aura:

```bash
python3 -B robot.py
```

Wait for `Aura is ready`, then say `Hello Aura`. The `-B` flag prevents Python from using stale bytecode while iterating over SSH.

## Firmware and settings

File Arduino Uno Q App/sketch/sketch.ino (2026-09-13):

#include <Arduino.h>
#include <Arduino_RouterBridge.h>

#include <U8g2lib.h>
#include <Wire.h>
#include <Servo.h>


// ============================================================
// L298N MOTOR PINS
// ============================================================

#define ENA  9
#define IN1  7
#define IN2  8

#define IN3  12
#define IN4  13
#define ENB  10


// ============================================================
// SERVO
// ============================================================

#define SERVO_PIN 6

Servo headServo;

int servoAngle = 90;

// Keep the head inside the mechanical limits of this robot.
const int SERVO_MIN = 55;
const int SERVO_MAX = 135;


// ============================================================
// MOTOR SETTINGS
// ============================================================

// The L298N can be driven harder from the manual UI, but 70 is the
// deliberately gentle speed used by this companion robot.
const int SAFE_MOTOR_SPEED = 70;
int motorSpeed = SAFE_MOTOR_SPEED;


// Timed motion is used by the voice controller. The deadline lives on the
// MCU, so a timed voice command still stops if Python disconnects.
bool timedMotionActive = false;
unsigned long timedMotionStopAt = 0;

bool LEFT_REVERSED  = false;
bool RIGHT_REVERSED = false;


// ============================================================
// OLED
// ============================================================

U8G2_SH1106_128X64_NONAME_F_HW_I2C u8g2(
  U8G2_R0,
  U8X8_PIN_NONE
);


// ============================================================
// EYE SETTINGS
// ============================================================

const int EYE_W = 42;
const int EYE_H = 42;

const int EYE_RADIUS = 10;

const int LEFT_BASE_X  = 11;
const int RIGHT_BASE_X = 75;

const int BASE_Y = 11;


// ============================================================
// EYE POSITION
// ============================================================

float eyeX = 0;
float eyeY = 0;

float targetX = 0;
float targetY = 0;


// ============================================================
// EYE OPENNESS
// ============================================================

float openness = 1.0;
float targetOpenness = 1.0;


// ============================================================
// MOODS
// ============================================================

enum EyeMood {

  NORMAL = 0,
  HAPPY = 1,
  ANGRY = 2,
  TIRED = 3,
  CURIOUS = 4

};

EyeMood currentMood = NORMAL;


// ============================================================
// AUTO EMOTION
// ============================================================

bool autoEmotion = true;

unsigned long nextEmotionTime = 8000;
unsigned long emotionEndTime = 0;

bool temporaryEmotion = false;


// ============================================================
// RANDOM LOOK
// ============================================================

unsigned long lastLook = 0;
unsigned long nextLook = 2000;


// ============================================================
// BLINK SETTINGS
// ============================================================

unsigned long lastBlink = 0;
unsigned long nextBlink = 3500;


// ============================================================
// NATURAL BLINK STATE
// ============================================================

enum BlinkState {

  BLINK_IDLE,
  BLINK_CLOSING,
  BLINK_CLOSED,
  BLINK_OPENING

};

BlinkState blinkState = BLINK_IDLE;

unsigned long blinkStartTime = 0;


// Natural blink timings

const unsigned long BLINK_CLOSE_TIME = 85;
const unsigned long BLINK_HOLD_TIME  = 30;
const unsigned long BLINK_OPEN_TIME  = 135;


// Double blink

bool waitingSecondBlink = false;

unsigned long secondBlinkAt = 0;


// ============================================================
// MOTOR - LEFT
// ============================================================

void setLeftMotor(int direction) {

  if (LEFT_REVERSED) {
    direction = -direction;
  }


  if (direction > 0) {

    digitalWrite(IN1, HIGH);
    digitalWrite(IN2, LOW);

    analogWrite(
      ENA,
      motorSpeed
    );
  }

  else if (direction < 0) {

    digitalWrite(IN1, LOW);
    digitalWrite(IN2, HIGH);

    analogWrite(
      ENA,
      motorSpeed
    );
  }

  else {

    digitalWrite(IN1, LOW);
    digitalWrite(IN2, LOW);

    analogWrite(
      ENA,
      0
    );
  }
}


// ============================================================
// MOTOR - RIGHT
// ============================================================

void setRightMotor(int direction) {

  if (RIGHT_REVERSED) {
    direction = -direction;
  }


  if (direction > 0) {

    digitalWrite(IN3, HIGH);
    digitalWrite(IN4, LOW);

    analogWrite(
      ENB,
      motorSpeed
    );
  }

  else if (direction < 0) {

    digitalWrite(IN3, LOW);
    digitalWrite(IN4, HIGH);

    analogWrite(
      ENB,
      motorSpeed
    );
  }

  else {

    digitalWrite(IN3, LOW);
    digitalWrite(IN4, LOW);

    analogWrite(
      ENB,
      0
    );
  }
}


// ============================================================
// WEB DRIVE
// ============================================================

bool drive(int left, int right) {

  // Legacy/manual drive intentionally remains latched until /stop. Voice
  // control uses moveTimed() below, which has an MCU-enforced stop.
  timedMotionActive = false;

  left = constrain(
    left,
    -1,
    1
  );

  right = constrain(
    right,
    -1,
    1
  );


  setLeftMotor(left);
  setRightMotor(right);


  return true;
}


// ============================================================
// STOP MOTORS
// ============================================================

bool stopMotors() {

  timedMotionActive = false;

  setLeftMotor(0);
  setRightMotor(0);

  return true;
}


// ============================================================
// MOTOR SPEED
// ============================================================

bool setSpeed(int speed) {

  motorSpeed =
    constrain(
      speed,
      0,
      SAFE_MOTOR_SPEED
    );


  Monitor.print(
    "Speed: "
  );

  Monitor.println(
    motorSpeed
  );


  return true;
}


// ============================================================
// TIMED MOTION
//
// Starts a move and lets loop() stop it after the requested time. This must
// be used for every non-continuous Gemini movement command.
// ============================================================

bool moveTimed(
  int left,
  int right,
  int durationMs
) {

  left = constrain(
    left,
    -1,
    1
  );

  right = constrain(
    right,
    -1,
    1
  );

  durationMs = constrain(
    durationMs,
    100,
    5000
  );

  setLeftMotor(left);
  setRightMotor(right);

  timedMotionStopAt =
    millis() +
    durationMs;

  timedMotionActive = true;

  Monitor.print(
    "Timed motion: "
  );

  Monitor.println(
    durationMs
  );

  return true;
}


// ============================================================
// SERVO
// ============================================================

bool setServo(int angle) {

  servoAngle =
    constrain(
      angle,
      SERVO_MIN,
      SERVO_MAX
    );


  headServo.write(
    servoAngle
  );


  Monitor.print(
    "Servo: "
  );

  Monitor.println(
    servoAngle
  );


  return true;
}


// ============================================================
// DRAW SINGLE EYE
// ============================================================

void drawEye(
  int x,
  int y,
  int width,
  int height,
  bool leftEye
) {

  // ==========================================================
  // CLOSED EYE
  // ==========================================================

  if (height <= 3) {

    int cy =
      y +
      EYE_H / 2;


    // Slightly curved / soft closed eyelid

    u8g2.drawHLine(
      x + 4,
      cy,
      width - 8
    );


    u8g2.drawPixel(
      x + 3,
      cy - 1
    );


    u8g2.drawPixel(
      x + width - 4,
      cy - 1
    );


    return;
  }


  // ==========================================================
  // NATURAL EYELID MOVEMENT
  //
  // 75% of the missing height is taken from the top,
  // instead of squeezing equally from top and bottom.
  // ==========================================================

  int missingHeight =
    EYE_H -
    height;


  int topOffset =
    (missingHeight * 3) /
    4;


  y +=
    topOffset;


  // ==========================================================
  // MAIN EYE
  // ==========================================================

  u8g2.setDrawColor(
    1
  );


  int radius =
    min(
      EYE_RADIUS,
      max(
        2,
        height / 4
      )
    );


  u8g2.drawRBox(
    x,
    y,
    width,
    height,
    radius
  );


  // ==========================================================
  // EXPRESSION CUTOUTS
  // ==========================================================

  u8g2.setDrawColor(
    0
  );


  // ----------------------------------------------------------
  // HAPPY
  // ----------------------------------------------------------

  if (currentMood == HAPPY) {

    u8g2.drawDisc(
      x + width / 2,
      y + height + 8,
      width / 2 + 5
    );
  }


  // ----------------------------------------------------------
  // ANGRY
  // ----------------------------------------------------------

  else if (currentMood == ANGRY) {

    if (leftEye) {

      u8g2.drawTriangle(

        x,
        y,

        x + width,
        y,

        x + width,
        y + 13

      );
    }

    else {

      u8g2.drawTriangle(

        x,
        y,

        x + width,
        y,

        x,
        y + 13

      );
    }
  }


  // ----------------------------------------------------------
  // TIRED
  // ----------------------------------------------------------

  else if (currentMood == TIRED) {

    int tiredCut =
      min(
        12,
        height / 3
      );


    u8g2.drawBox(
      x,
      y,
      width,
      tiredCut
    );
  }


  // ----------------------------------------------------------
  // CURIOUS
  // ----------------------------------------------------------

  else if (currentMood == CURIOUS) {

    if (leftEye) {

      int curiousCut =
        min(
          5,
          height / 5
        );


      u8g2.drawBox(
        x,
        y,
        width,
        curiousCut
      );
    }
  }


  u8g2.setDrawColor(
    1
  );
}


// ============================================================
// DRAW BOTH EYES
// ============================================================

void drawEyes() {

  u8g2.clearBuffer();


  int offsetX =
    (int)eyeX;


  int offsetY =
    (int)eyeY;


  int currentHeight =
    (int)(
      EYE_H *
      openness
    );


  currentHeight =
    constrain(
      currentHeight,
      0,
      EYE_H
    );


  int leftX =
    LEFT_BASE_X +
    offsetX;


  int rightX =
    RIGHT_BASE_X +
    offsetX;


  int y =
    BASE_Y +
    offsetY;


  drawEye(
    leftX,
    y,
    EYE_W,
    currentHeight,
    true
  );


  drawEye(
    rightX,
    y,
    EYE_W,
    currentHeight,
    false
  );


  u8g2.sendBuffer();
}


// ============================================================
// SMOOTH EYE POSITION
// ============================================================

void updateEyeMovement() {

  eyeX +=
    (
      targetX -
      eyeX
    ) *
    0.18;


  eyeY +=
    (
      targetY -
      eyeY
    ) *
    0.18;
}


// ============================================================
// SMOOTH STEP
// ============================================================

float smoothStep(float t) {

  t =
    constrain(
      t,
      0.0f,
      1.0f
    );


  return
    t *
    t *
    (
      3.0f -
      2.0f *
      t
    );
}


// ============================================================
// START BLINK
// ============================================================

void startBlink() {

  if (
    blinkState !=
    BLINK_IDLE
  ) {

    return;
  }


  blinkState =
    BLINK_CLOSING;


  blinkStartTime =
    millis();
}


// ============================================================
// NATURAL BLINK UPDATE
// ============================================================

void updateBlink() {

  unsigned long now =
    millis();


  unsigned long elapsed =
    now -
    blinkStartTime;


  // ==========================================================
  // IDLE
  // ==========================================================

  if (
    blinkState ==
    BLINK_IDLE
  ) {

    openness =
      1.0;

    return;
  }


  // ==========================================================
  // CLOSING
  // ==========================================================

  if (
    blinkState ==
    BLINK_CLOSING
  ) {

    float t =
      (float)elapsed /
      (float)BLINK_CLOSE_TIME;


    if (t >= 1.0) {

      openness =
        0.0;


      blinkState =
        BLINK_CLOSED;


      blinkStartTime =
        now;


      return;
    }


    float eased =
      smoothStep(t);


    openness =
      1.0 -
      eased;


    return;
  }


  // ==========================================================
  // CLOSED
  // ==========================================================

  if (
    blinkState ==
    BLINK_CLOSED
  ) {

    openness =
      0.0;


    if (
      elapsed >=
      BLINK_HOLD_TIME
    ) {

      blinkState =
        BLINK_OPENING;


      blinkStartTime =
        now;
    }


    return;
  }


  // ==========================================================
  // OPENING
  // ==========================================================

  if (
    blinkState ==
    BLINK_OPENING
  ) {

    float t =
      (float)elapsed /
      (float)BLINK_OPEN_TIME;


    if (t >= 1.0) {

      openness =
        1.0;


      blinkState =
        BLINK_IDLE;


      return;
    }


    float eased =
      smoothStep(t);


    openness =
      eased;


    return;
  }
}


// ============================================================
// LOOK FUNCTIONS
// ============================================================

void lookCenter() {

  targetX = 0;
  targetY = 0;
}


void lookLeft() {

  targetX = -8;
  targetY = 0;
}


void lookRight() {

  targetX = 8;
  targetY = 0;
}


void lookUp() {

  targetX = 0;
  targetY = -6;
}


void lookDown() {

  targetX = 0;
  targetY = 6;
}


// ============================================================
// RANDOM LOOK
// ============================================================

void randomLook() {

  int direction =
    random(
      0,
      9
    );


  switch (direction) {


    case 0:

      lookLeft();

      break;


    case 1:

      lookRight();

      break;


    case 2:

      lookUp();

      break;


    case 3:

      lookDown();

      break;


    case 4:

      targetX = -7;
      targetY = -5;

      break;


    case 5:

      targetX = 7;
      targetY = -5;

      break;


    case 6:

      targetX = -7;
      targetY = 5;

      break;


    case 7:

      targetX = 7;
      targetY = 5;

      break;


    default:

      lookCenter();

      break;
  }
}


// ============================================================
// SET EMOTION FROM WEB
//
// 0 = NORMAL
// 1 = HAPPY
// 2 = ANGRY
// 3 = TIRED
// 4 = CURIOUS
// 5 = AUTO
// ============================================================

bool setEmotion(int mood) {

  temporaryEmotion =
    false;


  // ==========================================================
  // AUTO MODE
  // ==========================================================

  if (mood == 5) {

    autoEmotion =
      true;


    currentMood =
      NORMAL;


    nextEmotionTime =
      millis() +
      random(
        4000,
        9000
      );


    Monitor.println(
      "Emotion: AUTO"
    );


    return true;
  }


  // ==========================================================
  // MANUAL MODE
  // ==========================================================

  autoEmotion =
    false;


  mood =
    constrain(
      mood,
      0,
      4
    );


  currentMood =
    (EyeMood)mood;


  lookCenter();


  Monitor.print(
    "Emotion: "
  );


  Monitor.println(
    mood
  );


  return true;
}


// ============================================================
// TEMPORARY EXPRESSION
//
// Used by Gemini for conversational reactions. When the expression expires,
// the face returns to its normal automatic behaviour rather than getting
// stuck in one mood.
// ============================================================

bool expressEmotion(
  int mood,
  int durationMs
) {

  mood = constrain(
    mood,
    0,
    4
  );

  durationMs = constrain(
    durationMs,
    500,
    5000
  );

  currentMood =
    (EyeMood)mood;

  autoEmotion = true;
  temporaryEmotion = true;

  emotionEndTime =
    millis() +
    durationMs;

  lookCenter();

  Monitor.print(
    "Expression: "
  );

  Monitor.println(
    mood
  );

  return true;
}


// ============================================================
// WEB BLINK
// ============================================================

bool webBlink() {

  startBlink();

  return true;
}


// ============================================================
// AUTO EMOTIONS
// ============================================================

void updateAutoEmotion() {

  if (!autoEmotion) {
    return;
  }


  unsigned long now =
    millis();


  // ==========================================================
  // RETURN TO NORMAL
  // ==========================================================

  if (
    temporaryEmotion &&
    now >= emotionEndTime
  ) {

    currentMood =
      NORMAL;


    temporaryEmotion =
      false;


    nextEmotionTime =
      now +
      random(
        5000,
        12000
      );
  }


  // ==========================================================
  // START RANDOM EMOTION
  // ==========================================================

  if (
    !temporaryEmotion &&
    now >= nextEmotionTime
  ) {

    int randomMood =
      random(
        1,
        5
      );


    currentMood =
      (EyeMood)randomMood;


    temporaryEmotion =
      true;


    emotionEndTime =
      now +
      random(
        800,
        1800
      );
  }
}


// ============================================================
// RANDOM BLINK HANDLING
// ============================================================

void updateRandomBlink() {

  unsigned long now =
    millis();


  // ==========================================================
  // SECOND BLINK
  // ==========================================================

  if (
    waitingSecondBlink &&
    blinkState ==
      BLINK_IDLE &&
    now >= secondBlinkAt
  ) {

    startBlink();


    waitingSecondBlink =
      false;


    return;
  }


  // ==========================================================
  // NORMAL RANDOM BLINK
  // ==========================================================

  if (
    blinkState ==
      BLINK_IDLE &&
    !waitingSecondBlink &&
    now - lastBlink >
      nextBlink
  ) {

    startBlink();


    lastBlink =
      now;


    nextBlink =
      random(
        2500,
        6500
      );


    // Approximately 20% chance
    // of a second quick blink.

    if (
      random(
        0,
        5
      ) == 0
    ) {

      waitingSecondBlink =
        true;


      secondBlinkAt =
        now +
        random(
          230,
          330
        );
    }
  }
}


// ============================================================
// SETUP
// ============================================================
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
void loop() {

  unsigned long now =
    millis();


  // The timed-move deadline is checked on the MCU, independently of the web
  // server and Gemini process.
  if (
    timedMotionActive &&
    (long)(now - timedMotionStopAt) >= 0
  ) {

    stopMotors();

    Monitor.println(
      "Timed motion stopped"
    );
  }


  // ==========================================================
  // SMOOTH EYE MOVEMENT
  // ==========================================================

  updateEyeMovement();


  // ==========================================================
  // BLINK
  // ==========================================================

  updateBlink();


  // ==========================================================
  // RANDOM BLINK / DOUBLE BLINK
  // ==========================================================

  updateRandomBlink();


  // ==========================================================
  // RANDOM LOOK
  // ==========================================================

  if (
    now -
    lastLook >
    nextLook
  ) {

    randomLook();


    lastLook =
      now;


    nextLook =
      random(
        900,
        2600
      );
  }


  // ==========================================================
  // AUTO EMOTIONS
  // ==========================================================

  updateAutoEmotion();


  // ==========================================================
  // DRAW OLED
  // ==========================================================

  drawEyes();


  delay(
    15
  );
}
